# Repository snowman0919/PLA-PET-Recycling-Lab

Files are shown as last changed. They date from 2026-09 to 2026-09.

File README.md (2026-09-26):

# PPR — 균일 직경 필라멘트를 위한 통합 재활용기
목표와 경계는 [KODEX.md](KODEX.md), 현재 증거·작업은 [STATUS.md](STATUS.md), 압출 방법 비교는 [품질 경로 결정 기록](docs/decisions/filament-quality-route.md)을 따른다.

제품 범위: 호퍼 → S1 2축 파쇄 → 선택 이송부 → S2 편심/역자전 분쇄 → 버퍼 → 수평 압출 → 냉각/직경 계측 → 가압 인출 → 장력 분리 권취.
최종 목표는 냉각 후 일정한 1.75mm 필라멘트를 경제적으로 만드는 것이다. 현재 연결 이송과 실제 필라멘트 생산 모두 미완료다.
상류 실패와 별개로 최종 제품의 같은 압출 모듈에 건조 기준 원료를 넣는 설계/디지털 시험을 진행할 수 있다. 전체 제품 성공과는 구분한다.

## 작업 자산
- c2.1/cad/PPR_VP1.step: 전체 기계 STEP
- c2.1/cad/PPR_C2_1_machine_integration.FCStd 및 c2.1/src/: 편집 원본/생성기
- c2.1/bom/system_bom.csv, .xlsx: 활성 BOM
- c2.1/firmware/, electrical/: 제어/전장 자산
- c2.2/sim/assets/usd/full_machine.usda: 대응 Isaac 장면
- c2.2/results/full_machine/layout_comparison.json: 기준안/재배치안 비교
- tests/, c2/tests/, c2.1/tests/, c2.3/tests/: 범위별 회귀 자산

재현은 해당 생성기/실행기의 --help와 결과의 원본 해시·설정을 사용한다. CAD/STEP, 충돌 메시/USD, BOM, 시험 결과를 같은 후보로 맞춘 후 해당 verify_artifacts를 수행한다.
역사 실험의 재실행이나 Graphify 완료를 새 제품 작업의 선행조건으로 만들지 않는다. 숫자·PASS 명칭은 당시 범위에서만 유효하다.
물리 제작·구매·통전·실물시험·main 병합은 사용자 승인 전 HOLD다. MIT 및 LICENSE-HARDWARE를 유지한다.

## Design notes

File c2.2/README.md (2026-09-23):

# C2.2 — VP1 전체 기계 Isaac Sim 검증

`c2.1/cad/PPR_VP1.step`을 전체 솔리드 단위로 변환해
`sim/assets/usd/full_machine.usda`에서 실제 조립 운동과 소재 경로를 검사한다.
현재 STEP/USD SHA와 최종 실행 결과는 루트 `STATUS.md`가 기준이다.

## 주요 경로

- `sim/assets/convert.py`: STEP 솔리드와 조립 이름을 STL/sidecar로 대응시킨다.
- `sim/full_machine.py`: S1/S2/오거/풀러/와인더의 종속 운동과 접촉을 실행한다.
- `sim/flow_localize.py`: 호퍼, S1 배출, 슈트, S2 입구를 단계별로 주입해
  실제 통과·정체·world 이탈을 구분한다.
- `sim/verify_full.py`: 전체 운동 추적, 접촉, 소재 경로 결과를 판정한다.
- `sim/render_reviewer_scenes.py`: 동일 USD/STEP에 묶인 검토 이미지 4장을 만든다.
- `results/full_machine/`: 최종 기계 판독 JSON, runner log, 이미지 증거.

## 검증 경계

이 시뮬레이션은 결함 발견과 디지털 운동/경로 검증이다. 파괴 물성, 처리량,
토크, 열, 마모, 수명과 안전 containment의 물리 적합성을 인증하지 않는다.
PSU는 24V 33A/명판 800W이며 500W는 소프트 목표, 792W는 강제 상한이다.
구매·제작·통전·물리 운전·main 병합은 명시적 승인 전 **HOLD**다.

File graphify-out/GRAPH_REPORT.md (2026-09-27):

# Graph Report - PPR-c2.1-codex-20260921  (2026-09-27)

## Corpus Check
- Incremental host semantic refresh: 2 current documents; corpus-wide statistics were not recomputed.

## Summary
- 2025 nodes · 3721 edges · 192 communities (107 shown, 85 thin omitted)
- Extraction: 92% EXTRACTED · 8% INFERRED · 0% AMBIGUOUS · INFERRED: 301 edges (avg confidence: 0.87)
- Token cost: 0 input · 0 output

## Community Hubs (Navigation)
- architectures.py
- process_model.py
- c2/src/build_cad.py
- verify_contract.py
- guards.py
- EvidenceTests
- drive_teeth.py
- winder.py
- c2.1/src/build_cad.py
- test_telemetry.py
- S2
- i6_surrogate.py
- downstream.py
- run_one_phase
- flow_localize.py
- electrical_bay.py
- convert.py
- test_contract.py
- filament-quality-route.md
- cadquery
- generate
- Inputs
- s1_event
- components
- run_study.py
- engineering.py
- relocated_gravity.py
- bond_manager.py
- test_r03_causality.py
- d4_accounting.py
- run_case.py
- design.py
- render_reviewer_scenes.py
- approx
- main
- C2 Engineering Contracts
- Controller
- os
- ControllerTests
- i3_coupon.py
- PPR C1 Dimensioned Engineering Review Package
- make_drawings.py
- DesignContracts
- controller_core.cpp
- structural_screen.py
- Outputs
- build_machine_integration.py
- chute.py
- build_freecad.py
- analyze.py
- C2.1 S2 Transmission Schematic
- d2_torque.py
- BondManager
- VP1 whole-machine Isaac Sim validation
- csv
- bonds.py
- ADR-002: VP1 체인 경로 vs 동결된 C1 구조물 릴리프 (chain routing reliefs)
- InvalidMechanism
- run_r1.py
- TestVerifier
- Open Physical Actions Register
- _box
- ProcessModelPhysicsTests
- run_r4_t2b.py
- PPR KODEX — 쓸 수 있는 필라멘트를 만드는 가상제품
- auger_shaft
- _prism_xz
- TestD4Ledger
- hopper_panels.py
- run_r2.py
- Fail-Closed Thermal and Jam Control Reference
- DownstreamGeometryTests
- emit_usd.py
- C2.3-A-R3 리뷰 핸드오프 (판정 요청)
- d0_clock.py
- json
- C2.3-A-R1 수렴 재실행 핸드오프 (판정 요청)
- d1_contact.py
- PPR_C2_1_machine_wiring_erc.json
- TestNullStatus
- pan_floor
- _feed_gear
- REVIEW HANDOFF — C2.3-R1 진단 결과 (판정 요청)
- PPR C1 CAD Inspection Image
- hashlib
- Limits
- run_r3.py
- i4_screen.py
- C2.2 핸드오프 — 2층 구조: (a) I0–I6 numpy 프록시 + (b) C2.2b headless PhysX 동역학 Gates A–F
- MissingEvidenceError
- Single-Input Reverse-Output S2 Drivetrain
- worm_sleeve
- power_sim.py
- VP1 current STEP FreeCAD USD BOM assembly
- test_surrogate.py
- STATUS.md
- test_benchmark.py
- C2.2 VP1 실행 씬 출처와 증거 경계
- Fixed C2 System Constraints
- build_machine_wiring.py
- Active C2 Baseline
- FeedbackTests
- C2.2 — VP1 전체 기계 Isaac Sim 검증
- build_system_bom.py
- d3_bond.py
- c2/src/verify_artifacts.py
- REFERENCE/UNRATED worm, wheel, shafts, bearings and motor
- Shared M1 one-degree-of-freedom S1/S2 drive
- check_admissible
- convergence/manifest.json
- r2/manifest.json
- r3/manifest.json
- screen_open_area
- C1 Digital Contracts
- Stage 5 active chute auger
- Function-preserving integration reliefs
- Four-turn auger and transverse screw active chute
- Donor PSU and stop button reported, system cost still unquoted
- s2a_direction_phi
- TestD4Faults
- 24V 33A PSU, 500W soft target and 792W current ceiling
- Digital verification is not physical approval
- VP1 integrated product hard goal
- Clause A1 (Steps-per-run)
- Clause A2 (Metrics calculation)
- Clause A3 (Mass conservation)
- Clause A4 (Missing-event handling)
- Clause A5 (Scene provenance)
- Clause A6 (Break/fragment accounting)
- Clause A7 (Threshold applicability)
- Host-tested firmware power allocation
- Param Trace Document
- Amendment Log
- CONTRACT (superseded)
- Contract Baseline Cutter Gap
- Contract Baseline q
- Contract Baseline Screen Aperture
- Next Checkpoint Plan
- Requirements Evidence
- Review Handoff Summary
- CONTRACT R1
- Conservative cycloidal pin-ring screen
- Material Calibration Evidence
- Motor and Driver RFQ Evidence
- Unsubmitted DEM Job Queue
- C2 Research and CAD Dependencies
- Contact impulse threshold
- Convergence metrics
- Coupling Window Radius
- dt ladder values
- Forbidden actions in R0
- Fragment / bond-break count threshold
- Baseline S1-A (twin-shaft hook shear)
- Baseline S2-A (q=8, e=7 mm)
- Cutter gap
- Impulse scale
- Friction / gravity / solver iterations
- Initial poses
- Screen aperture
- Frozen waste cases (FDM, PURGE, WRAP)
- Goal R0 §2 (Numerical reliability closure)
- Hopper Interior Geometry
- ISAAC_PHYSX backend
- Kinematic Frame F0 Definition
- C2.3 tribometer, crown and joint expansion stopped
- Real-geometry candidate validation method
- Machine Body Dimensions
- Mass conservation threshold
- Motion Law Equations
- Nominal Motion Parameters
- Revision R1
- BLOCKED_PERFORMANCE_DATA
- Required artifacts list
- Residence time threshold
- S1 Cutter Parameters
- S2 Local Frame Definition
- Shaft work threshold
- 가상 품질·비용 비교 (실물 성능 아님)
- comparison_contract
- 6. 경제성 및 다음 작업

## God Nodes (most connected - your core abstractions)
1. `components()` - 41 edges
2. `S2` - 32 edges
3. `Inputs` - 31 edges
4. `Transmission` - 30 edges
5. `BondManager` - 26 edges
6. `_box()` - 26 edges
7. `components()` - 23 edges
8. `generate()` - 22 edges
9. `s1_event()` - 22 edges
10. `_cyl()` - 22 edges

## Surprising Connections (you probably didn't know these)
- `Small Pin-Ring Feasibility Screen` --semantically_similar_to--> `S2 Cycloidal Guide, Sleeve, and Pin Rings`  [INFERRED] [semantically similar]
  c2/docs/C2_ENGINEERING_NOTES.md → drawings/PPR_C1_dimensioned_review.pdf
- `Short clutch fault is not rescued by feedback` --semantically_similar_to--> `Isolated modeled winding-clutch fault`  [INFERRED] [semantically similar]
  STATUS.md → docs/decisions/filament-quality-route.md
- `Frozen C1 Baseline` --conceptually_related_to--> `PPR C1 Dimensioned Engineering Review Package`  [INFERRED]
  README.md → drawings/PPR_C1_dimensioned_review.pdf
- `Evidence and Safety Boundaries` --semantically_similar_to--> `Safety-Preserving Cost Reduction Order`  [INFERRED] [semantically similar]
  AGENTS.md → c2/docs/CALIBRATION_AND_RFQ.md
- `Open Physical Actions Register` --semantically_similar_to--> `Nominal Drawing Fabrication Hold`  [INFERRED] [semantically similar]
  c2.1/docs/OPEN_ACTIONS_KO.md → c2.1/drawings/PPR_C2_1_P6_nominal_plate_review.pdf

## Import Cycles
- None detected.

## Hyperedges (group relationships)
- **Connected material-route verification boundary** — c2_1_docs_adr_002_chain_routing_active_auger, c2_1_docs_adr_002_chain_routing_cross_feed_shaft, c2_1_docs_adr_002_chain_routing_connected_transport_hold, c2_2_readme_flow_localization [EXTRACTED 1.00]
- **C1 RFQ-Only Dimensioned Drawing Set** — drawings_ppr_c1_dimensioned_review_drive_and_bearing_plates, drawings_ppr_c1_dimensioned_review_s1_cutter_system, drawings_ppr_c1_dimensioned_review_s2_cycloidal_components, drawings_ppr_c1_dimensioned_review_interface_and_fit_schedules [EXTRACTED 1.00]
- **C2 and C2.1 Numerical Evidence CI Pipeline** — _github_workflows_c2_engineering_c2_numerical_study_step, _github_workflows_c2_engineering_c2_unit_tests_step, _github_workflows_c2_engineering_gp_performance_training_step, _github_workflows_c2_engineering_mlp_performance_training_step, _github_workflows_c2_engineering_c2_artifact_verification_step, _github_workflows_c2_engineering_c2_1_transmission_step, _github_workflows_c2_engineering_c2_1_unit_tests_step, _github_workflows_c2_engineering_c2_1_artifact_verification_step [EXTRACTED 1.00]
- **C2 P5 Thermal and Control Evidence** — c2_docs_c2_engineering_notes_s2_thermal_development_module, c2_docs_c2_engineering_notes_five_node_thermal_circuit, c2_docs_c2_engineering_notes_cad_derived_heat_capacity_bounds, c2_docs_c2_engineering_notes_cooling_fault_sensitivity, c2_docs_c2_engineering_notes_fail_closed_control_reference, c2_docs_c2_engineering_notes_independent_hardware_safety_chain, c2_docs_c2_engineering_notes_p5_digital_thermal_control_boundary [EXTRACTED 1.00]
- **C2 Performance Evidence Gate** — c2_docs_c2_engineering_notes_performance_job_manifest, c2_docs_c2_engineering_notes_qualified_performance_learning_pipeline, c2_docs_c2_engineering_notes_blocked_performance_data, c2_docs_c2_engineering_notes_material_calibration_plan [EXTRACTED 1.00]
- **C2 S2 Geometry Decision Flow** — c2_docs_c2_engineering_notes_s2_parameter_search, c2_docs_c2_engineering_notes_geometry_assembly_screen, c2_docs_c2_engineering_notes_small_pin_ring_feasibility, c2_docs_c2_engineering_notes_split_dual_path_alternative [EXTRACTED 1.00]
- **Diagnostic Outcomes relate to Requirements** — c2_3_revisions_r1_diagnostic_summary [INFERRED 0.85]
- **Digital Evidence Without External Hardware Release** — _github_workflows_c2_engineering_no_hardware_approval_gate, _github_workflows_c2_engineering_dynamic_evidence_count_contract, _github_workflows_c2_engineering_procurement_fabrication_energization_hold_contract [INFERRED 0.95]

## Communities (192 total, 85 thin omitted)

### Community 0 - "architectures.py"
Cohesion: 0.22
Nodes (16): validate_mechanisms(), Architecture, check_baseline_present(), check_clearance(), check_direction(), I4 mechanism architecture library (Isaac-independent, numpy-free). 7 variants:…, _s1a(), _s1b() (+8 more)

### Community 1 - "process_model.py"
Cohesion: 0.05
Nodes (57): build_library(), library_for_source(), main(), Build the same C++ PI kernel used by the host controller self-test., Avoid stale shared code in process-model calculations., _add(), chute_checks(), _dist_to_s2() (+49 more)

### Community 2 - "c2/src/build_cad.py"
Cohesion: 0.21
Nodes (15): Any, box(), cylinder(), from_c1(), main(), primitive(), C2 S2 thermal/fixed-shear development module. Not an assembly release. C1…, sector() (+7 more)

### Community 3 - "verify_contract.py"
Cohesion: 0.06
Nodes (45): Gate F follow-on: refit surrogate anchors on REAL dynamics data (additive).…, _load(), Gate A-F dynamics contract tests (no SimulationApp: manifest/schema only)., A reused STL path erased the south S1 tread in the executable scene., test_dt_sweep_complete(), test_full_machine_compound_solids_have_distinct_contact_meshes(), test_gap_screen_sweep_complete(), test_s1_runs_real_physics() (+37 more)

### Community 4 - "guards.py"
Cohesion: 0.18
Nodes (16): _box(), components(), guard_chain_a(), guard_chain_b(), guard_lid_interlock_seat(), guard_s2_ring(), VP1 Stage 2: containment guards and lid-interlock seat. Replaces the…, Named guard parts in absolute machine coordinates (group 'guard'). (+8 more)

### Community 5 - "EvidenceTests"
Cohesion: 0.13
Nodes (11): evidence_inventory(), EvidenceError, main(), nondominated(), ndarray, Path, ValueError, training_gate() (+3 more)

### Community 6 - "drive_teeth.py"
Cohesion: 0.09
Nodes (40): legacy_parts(), chain_length_mm(), gear_center_distance(), gear_pitch_radius(), ratio_chain(), Pure kinematics/math for the VP1 common drive — NO cadquery dependency. Split…, Transverse pitch radius of a helical gear (normal module mn)., External tangent construction in XZ. Returns the two touch-point 4-tuples, the… (+32 more)

### Community 7 - "winder.py"
Cohesion: 0.06
Nodes (63): _box(), components(), _cyl(), _flange(), _idler_z(), nip_opening_mm(), nip_range_mm(), pull_cool_mount() (+55 more)

### Community 8 - "c2.1/src/build_cad.py"
Cohesion: 0.06
Nodes (68): analytical_bounds(), c2_process_part(), cad_frame_check(), collision_checks(), components(), cylinder(), export_assembly(), extrude_xz() (+60 more)

### Community 9 - "test_telemetry.py"
Cohesion: 0.09
Nodes (15): aggregate(), load_run(), A2 aggregate: telemetry.jsonl + events.jsonl -> derived quantities. Mass:…, reject_proxy(), ledger(), load_run(), A2 partial mechanical energy ledger (NEVER claims closure). residual = W_in -…, A2 telemetry/analysis tests (>=10): integrals, mass, ledger, convergence, proxy… (+7 more)

### Community 10 - "S2"
Cohesion: 0.15
Nodes (11): design_set(), generalized_torque(), hook_polygon(), kinematics(), point_jacobian(), polygon_area(), ndarray, Six polar controls per hook; linear interpolation is manufacturable, not… (+3 more)

### Community 11 - "i6_surrogate.py"
Cohesion: 0.12
Nodes (23): bo_search(), build_pareto(), dominates(), evaluate_on_rows(), features(), load_i5_rows(), main(), pareto_front() (+15 more)

### Community 12 - "downstream.py"
Cohesion: 0.11
Nodes (30): _bounds(), _box(), build_result(), components(), cool_duct(), cool_fan_3_ref(), _cyl(), gauge_contact_a() (+22 more)

### Community 13 - "run_one_phase"
Cohesion: 0.07
Nodes (23): buffer_throat_contains(), gravity_mouth_contains(), gravity_receiver_contains(), hole_transition(), main(), Path, Return (candidate, completed_hole) for one descending physics step. The…, Sphere envelope inside the actual octagonal Ø13 lower clear throat. (+15 more)

### Community 14 - "flow_localize.py"
Cohesion: 0.15
Nodes (13): FIX A: material-flow localization for the integrated PPR VP1 machine. The last…, # NOTE: the contact-report event stream (subscribe_contact_report_, body_of(), Full-machine motion verification under Isaac Sim 6.1 headless PhysX. Loads the…, Classify a collision prim path into a body token., # NOTE: extra_args is the only channel that reaches the kit process —, bbox(), build() (+5 more)

### Community 15 - "electrical_bay.py"
Cohesion: 0.15
Nodes (24): _box(), components(), contactor(), current_limiter(), din_rail(), driver(), driver_1(), driver_2() (+16 more)

### Community 16 - "convert.py"
Cohesion: 0.11
Nodes (24): _bbox(), candidate_manifest(), _candidate_mass_properties(), _candidate_parts(), git_head(), _lod_of(), main(), Path (+16 more)

### Community 17 - "test_contract.py"
Cohesion: 0.09
Nodes (13): check_executor_label(), _forbidden_labels(), A1 contract tests (stdlib unittest, goal section 22). Banned terminal labels…, Accept only the Isaac Sim / PhysX backend descriptor., Proxy records (analytic diagnostic only) are inadmissible., reject_proxy(), rel_change(), rel_mass_error() (+5 more)

### Community 18 - "filament-quality-route.md"
Cohesion: 0.15
Nodes (14): 269 mm formation-to-gauge feedback dead time, Modeled two-axis observed and true qualification gate, Single-pass feedback A, optional reheating B, same-hardware fixed C comparison, Isolated S2 injection has three same-bore-to-buffer passages, not connected feed, 1. 사용자 결정과 작업 상태, 2. 조사에서 실제로 확인한 것, 3. 현재의 가성비 유력 기준안과 비교, 4. 간단하지만 제품과 연결된 모델 (+6 more)

### Community 19 - "cadquery"
Cohesion: 0.10
Nodes (8): ChainGeometry, ChuteGeometry, GearGeometry, GearRatioKinematics, skipUnless, VP1 Stage 1: real drivetrain geometry + S1->S2 chute tests. CAD-dependent tests…, Tooth-count kinematics recomputed from design/parameters.json., cadquery

### Community 20 - "generate"
Cohesion: 0.12
Nodes (11): build_bond_list(), cell_lattice(), main(), Recover lattice (nx,ny,nz,dx,dy,dz) by regenerating the specimen., Rebuild 6-neighbourhood lattice bonds matching bonds.lattice_graph., generate(), main(), random_quaternion() (+3 more)

### Community 21 - "Inputs"
Cohesion: 0.07
Nodes (27): Inputs, aux_demand_W, band_rotation_ms, buffer_full, estop_closed, fan_required, fan_tach_ok, gauge_major_mm (+19 more)

### Community 22 - "s1_event"
Cohesion: 0.15
Nodes (17): BenchmarkError, _equiv_dims(), _load_dir_for_arch(), main(), RuntimeError, I5 low-resolution end-to-end S1->S2 benchmark (Isaac-independent, numpy).…, Run S1 fracture event; return dataset record + fragment list. threshold_scale…, Feed IDENTICAL saved S1 fragments through S2 arch screen model. eff_scale… (+9 more)

### Community 23 - "components"
Cohesion: 0.12
Nodes (24): auger_bearings(), belt_bearings(), belt_chain(), belt_drum(), belt_follower_sprocket(), components(), cross_feed_bearings(), cross_feed_shell() (+16 more)

### Community 24 - "run_study.py"
Cohesion: 0.17
Nodes (13): Carry thermal state through batch/fan-fault segments; still uncalibrated., Lower-bound heat capacities from generated C2 metal volumes, not measured…, Thermal, thermal_capacities_from_cad(), thermal_duty_run(), thermal_matrix(), thermal_run(), _canon() (+5 more)

### Community 25 - "engineering.py"
Cohesion: 0.19
Nodes (13): diverse_selection(), equivalent_motor_load(), main(), Path, C2 deterministic engineering study. Numerical assumptions are not test evidence., write_json(), fit_gp(), fit_mlp() (+5 more)

### Community 26 - "relocated_gravity.py"
Cohesion: 0.25
Nodes (14): at_box(), gravity_parts(), loft_section(), main(), nominal_mass(), other_parts(), pairs(), Independent, non-release relocated S2 gravity-handoff alternative. Runs against… (+6 more)

### Community 27 - "bond_manager.py"
Cohesion: 0.13
Nodes (15): _components(), find(), union(), FractureInputError, FractureResult, Fragment, NonphysicalError, RuntimeError (+7 more)

### Community 28 - "test_r03_causality.py"
Cohesion: 0.13
Nodes (5): R0.3 causality/accounting unit tests (system python3, isaac-free). >= 10 tests:…, TestAtomicVsComponent, TestD3Distinguishability, TestDiagConstants, TestTimedDisable

### Community 29 - "d4_accounting.py"
Cohesion: 0.16
Nodes (19): compare_metrics(), _isaac_child(), jam_status(), main(), make_buckets(), ordered_sum(), passage_status(), D4 observability / accounting / negative tests (Goal R0 section 4, D4). Isaac… (+11 more)

### Community 30 - "run_case.py"
Cohesion: 0.15
Nodes (19): build_run_config(), dt_label(), dt_source_mapping(), finalize(), _import_s1(), main(), prepare(), A2 single-case Isaac headless runner (ONE frozen case + ONE ladder dt). REUSE… (+11 more)

### Community 31 - "design.py"
Cohesion: 0.13
Nodes (12): copy, box(), cyl(), part(), plate(), PPR C1 dimensional master. Generates a backend-neutral constructive-solid model., ring(), write_all() (+4 more)

### Community 32 - "render_reviewer_scenes.py"
Cohesion: 0.18
Nodes (17): isaac_capture(), look_at_matrix(), main(), probe_positions(), Path, Reviewer scenes for the PPR VP1 full machine (c2.2 acceptance item 2). Renders…, Use only a connected probe run for this exact STEP and USD., RTX attempt with a disk heartbeat. Kit quirk on this host: exceptions raised… (+9 more)

### Community 33 - "approx"
Cohesion: 0.16
Nodes (5): approx(), TestBoundaryWork, TestD0SubstepMapping, TestD1UnitRule, TestShaftTorque

### Community 34 - "main"
Cohesion: 0.12
Nodes (20): main(), mesh_volume(), Path, FIX B(1): convex-hull fidelity audit for the integrated machine. For every…, Signed volume of a closed triangle mesh via the divergence theorem (mm^3). CAD-…, Sample a centre and 16 rim rays of each Ø3 screen exit in mesh XY., screen_vertical_mesh_paths(), sha256_file() (+12 more)

### Community 35 - "C2 Engineering Contracts"
Cohesion: 0.11
Nodes (18): Run C2.1 Artifact Verification, Run C2.1 Transmission Analysis, Run C2.1 Unit Tests, Run C2 Artifact Verification, C2 Engineering Contracts, Run C2 Numerical Study, Run C2 Unit Tests, Actual Run Counts Must Equal Dynamic Evidence Inventory Counts (+10 more)

### Community 36 - "Controller"
Cohesion: 0.12
Nodes (18): Controller, BAND_ROTATION_PERIOD_MS, command_, gauge_gate_, gauge_seen_, integral_, latched_, limits_ (+10 more)

### Community 37 - "os"
Cohesion: 0.13
Nodes (12): argparse, Gate A loader: open c2.2/sim/assets/usd/machine.usda headless, report stage…, fail(), main(), I0 SimulationApp smoke: headless stage + one rigid cube, 60 physics steps. Gate…, # NOTE: close() os._exit()s via fast shutdown on success, so the JSON, Gate B: PhysX S1 twin-shaft (S1-A) + waste fragment clusters + breaking bonds.…, # NOTE: NO use_backend("tensor") scope: the ContactSensor (+4 more)

### Community 38 - "ControllerTests"
Cohesion: 0.15
Nodes (5): allocate_power(), Controller, Reference admission only; PSU 792 W rating does not raise this budget., controller(), ControllerTests

### Community 39 - "i3_coupon.py"
Cohesion: 0.19
Nodes (13): check_ordering(), load_dir_for(), main(), OrderingError, RuntimeError, I3 single-event fracture smoke benchmark (Isaac-independent, numpy-only). 12…, Fixed-lattice probe: identical geometry+seed, class strengths vary. Elementwise…, P0/P1 strand bundles carry no fracture claim (wrap risk only). (+5 more)

### Community 40 - "PPR C1 Dimensioned Engineering Review Package"
Cohesion: 0.12
Nodes (17): BLOCKED_PERFORMANCE_DATA, C1-SEED Comparison Point, Coupled Kinematic Work Model, Eccentric Sleeve Wall Constraint, Geometry and Assembly Screen, PLA PET and TPU Calibration Plan, 144-Job Performance Manifest, Qualified GP and MLP Performance Learning Pipeline (+9 more)

### Community 41 - "make_drawings.py"
Cohesion: 0.21
Nodes (16): ezdxf, reportlab_lib_pagesizes, reportlab_pdfbase, reportlab_pdfbase_ttfonts, reportlab_pdfgen, shapely_ops, dim(), drawshape() (+8 more)

### Community 43 - "controller_core.cpp"
Cohesion: 0.16
Nodes (15): algorithm, array, band_count(), diameter_pi_step(), main(), PowerDevice, name, W (+7 more)

### Community 44 - "structural_screen.py"
Cohesion: 0.19
Nodes (14): ast, bending_point(), case(), flange_thickness(), literal_dict_assignment(), margin(), Bounded, non-qualifying structural and thermal screen for VP1 hardware. Run:…, Read dimension constants without importing CadQuery or regenerating CAD. (+6 more)

### Community 45 - "Outputs"
Cohesion: 0.14
Nodes (14): Outputs, admitted_W, aux_enable, fans_enable, gauge_in_tolerance, h100_enable, h60_enable, m1_enable (+6 more)

### Community 46 - "build_machine_integration.py"
Cohesion: 0.18
Nodes (17): assembly_geometry_checks(), imported(), bbox_overlap(), bounds(), c21_parts(), collision_audit(), extent(), main() (+9 more)

### Community 47 - "chute.py"
Cohesion: 0.15
Nodes (12): bypass_channel_floor(), cutter_sweep_solids(), _guide(), _prism_xy(), VP1 Stage 1: real transfer chute from the S1 discharge opening to the C2.1 S2…, Conservative S1 cutter sweep envelopes for clearance checks., No stationary ribs in the screw pickup or flight zone., Longitudinal U cradle, opened locally into the powered cross pickup. The old… (+4 more)

### Community 48 - "build_freecad.py"
Cohesion: 0.23
Nodes (11): main(), Create the native FreeCAD C2.1 machine assembly from checked STEP parts., read_shape(), freecad, part, build(), face(), primitive() (+3 more)

### Community 49 - "analyze.py"
Cohesion: 0.12
Nodes (19): main(), Gate F: real gap x screen sweep on survivors (thin driver). S1 gap sweep: shaft…, run(), itertools, scipy_linalg, scipy_optimize, shapely_geometry, allocate() (+11 more)

### Community 50 - "C2.1 S2 Transmission Schematic"
Cohesion: 0.15
Nodes (15): F0 Coordinate Frame: +X Right, +Y Shaft Axis, +Z Up, C2.1 S2 Transmission Schematic, Elastic Sharing, Ratings, and Fabrication HOLD, Fixed q+1 Ring Pins and Reaction, Front Input Support, M1 Input Shaft +ω, Nominal Window Clearance extra0.20mm, Not a Generated CAD Section (+7 more)

### Community 51 - "d2_torque.py"
Cohesion: 0.21
Nodes (14): boundary_work(), _cross(), _dot(), _isaac_child(), on_post(), main(), D2 torque/work semantics diagnostic (Goal R0 section 4, D2). Definitions…, Axial contact torque on ONE shaft. contacts: iterable of (position_p,… (+6 more)

### Community 52 - "BondManager"
Cohesion: 0.18
Nodes (11): BondManager, Deterministic fallback fracture over a BondGraph., fixed_lattice(), I3 fracture regressions: determinism, conservation, orderings, gaps. Evidence:…, TestDeterminism, TestInvalidInput, TestMassConservation, TestOrientationDependence (+3 more)

### Community 53 - "VP1 whole-machine Isaac Sim validation"
Cohesion: 0.14
Nodes (14): Connected particulate transport HOLD, CROSS_FEED_SHAFT transverse screw, Rear output plate feed-mount clearance, S2 negative-direction geometry sweep, Historical proxy-result exclusion, Development PR versus physical-release policy, VP1 STEP/USD and result provenance, Stage-wise material flow localization (+6 more)

### Community 54 - "csv"
Cohesion: 0.18
Nodes (7): Verify the C2.1 P0-P6 digital package without granting hardware approval., csv_rows(), InventoryCostTests, Reported donor and stop-button inventory is not qualified stock., csv, xml_etree_elementtree, zipfile

### Community 55 - "bonds.py"
Cohesion: 0.15
Nodes (13): graph_from_meta(), Rebuild the exact I2 lattice from waste_gen metadata. Mirrors…, Bond, BondGraph, Cell, lattice_graph(), I2 bond-graph: cells/chunks + directional bonds (nominal strengths only).…, 6-neighbourhood lattice; x->in_raster, y->cross_raster, z->inter_layer_z. Cell… (+5 more)

### Community 56 - "ADR-002: VP1 체인 경로 vs 동결된 C1 구조물 릴리프 (chain routing reliefs)"
Cohesion: 0.15
Nodes (12): ADDENDUM (2026-09-22, VP1 Stage 4, rev B — SUPERSEDES the rev A decision), ADDENDUM 3 (2026-09-23, VP1 Stage 5 활성 오거 — 연결 이송 HOLD), ADDENDUM 4 (2026-09-23, VP1 횡방향 이송과 S2 출력 지지판), ADR-002: VP1 체인 경로 vs 동결된 C1 구조물 릴리프 (chain routing reliefs), REV B 부록 2 (2026-09-22, Isaac 통합 피드백 2건), 검증 경계와 HOLD, 결정 (rev B), 결정 (부품별) (+4 more)

### Community 57 - "InvalidMechanism"
Cohesion: 0.18
Nodes (10): main(), screen_candidate(), check_envelope(), get(), InvalidMechanism, ValueError, Zero clearance, bad direction sign, missing baseline, bad envelope., TestEnvelope (+2 more)

### Community 58 - "run_r1.py"
Cohesion: 0.23
Nodes (10): build_case_geometry(), _isaac_child(), main(), R1 runner: one canonical case at ONE ladder dt, equal 2.4 s physics. Contract:…, # NOTE: Gf.Vector3f hard-crashes (SIGSEGV) in this Isaac build;, # NOTE: work integral requires tau_shaft from typed contacts;, Deterministic per-case fragment positions from waste_gen dims., run_case_dt() (+2 more)

### Community 60 - "Open Physical Actions Register"
Cohesion: 0.17
Nodes (12): C2.1 Digital Assembly Service and Test Package, Lockout and Staged Physical Test, DIGITAL_P0_P6_PACKAGE_PASS_PHYSICAL_RELEASE_HOLD, P6 Full Machine Digital Integration, Remaining Rating and Performance Holds, Motor Floor Exceeds System Soft Budget, Open Physical Actions Register, C2.1 P0-P6 Integration Plan (+4 more)

### Community 61 - "_box"
Cohesion: 0.17
Nodes (12): _box(), bypass_wall_north_lower(), bypass_wall_south(), guide_left(), guide_right(), South containment, relieved only at the low-y spur-gear face., North containment ends before the orthogonal screw's west cheek., Central lane wall; transverse screw supplies lateral transport. (+4 more)

### Community 63 - "run_r4_t2b.py"
Cohesion: 0.17
Nodes (9): R4-T2b: chain suspended via end posts (FixedJoint), NO pin, gravity + preload…, isaacsim, isaacsim_core_experimental_objects, isaacsim_core_experimental_prims, isaacsim_core_experimental_utils_stage, isaacsim_core_simulation_manager, omni_physx, omni_timeline (+1 more)

### Community 64 - "PPR KODEX — 쓸 수 있는 필라멘트를 만드는 가상제품"
Cohesion: 0.18
Nodes (10): PPR KODEX — 쓸 수 있는 필라멘트를 만드는 가상제품, Hard Rules, 현재 상태와 방법, 목표, 산출과 인수, 품질·가성비 방향, Chiron donor reuse and reference pellet procurement boundary, C2.1 Active Digital Iteration (+2 more)

### Community 65 - "auger_shaft"
Cohesion: 0.25
Nodes (11): auger_shaft(), _cross_feed_flight(), cross_feed_shaft(), _helix_z(), _path_frame(), Split shaft with a swept, opposite-hand screw and keyed spur., Point and unit tangent at the initial vertex of a swept helix., Single right-hand helicoid with a 3 mm swept flight face. (+3 more)

### Community 66 - "_prism_xz"
Cohesion: 0.13
Nodes (15): belt_loop(), capsule(), intake_lip(), _prism_xz(), Historical ratchet rib retained for inspection, not installed., Historical pan-only ribs, superseded by the active transfer design., 45deg intake lip under the S1 -X side strip (the opening's west edge); all…, Two side loops leave a continuous, separately driven central lane. (+7 more)

### Community 68 - "hopper_panels.py"
Cohesion: 0.40
Nodes (9): _bore(), components(), _inner_y(), _nut_boss(), Split the historical C1 hopper BRep into bounded PC panels and steel seam…, Return two distinct PC print solids and two steel bolted seam straps. The split…, _strap(), ocp_brepextrema (+1 more)

### Community 69 - "run_r2.py"
Cohesion: 0.29
Nodes (8): R2 Review Handoff Summary, build_case_geometry(), _isaac_child(), main(), R2 runner: per-physics-step contact stream + signed shaft load + boundary work…, run_case_dt(), run_paths(), sha256_file()

### Community 70 - "Fail-Closed Thermal and Jam Control Reference"
Cohesion: 0.25
Nodes (11): CAD-Derived Heat-Capacity Lower Bounds, Clean-Air Cooling Path, Clean Filter, Clogged Filter, and Fan-Failure Sensitivity, Fail-Closed Thermal and Jam Control Reference, Five-Node Chamber and Drivetrain Thermal Circuit, Fixed-Shear Sensor Path, Independent Hardware Safety Chain, P5 Digital Thermal and Control Boundary (+3 more)

### Community 72 - "emit_usd.py"
Cohesion: 0.36
Nodes (9): box_mesh(), convex_hull_of_verts(), git_head(), load_stl_verts_faces(), main(), mesh_prim(), Path, Gate A: machine USD emission from staged STL + parametric DERIVED transfer… (+1 more)

### Community 73 - "C2.3-A-R3 리뷰 핸드오프 (판정 요청)"
Cohesion: 0.20
Nodes (9): 1. R3 결과 요약, 2. T1 상세 (5% GATE_MET), 3. T2 BLOCKED 상세 (픽스처 반복 이력), 4. 리뷰어 지시 반영 상태, 5. 미해결 (리뷰어 승인 필요), 6. 실행자 결론 불가, 7. CI 상태 (정확 커밋 a431df75), 8. R4-T2b 추가 반복 (리뷰어 승인 fixture 변경 실행 결과) (+1 more)

### Community 74 - "d0_clock.py"
Cohesion: 0.31
Nodes (7): _isaac_child(), main(), D0 clock + 2.4 s horizon diagnostic (Goal R0 section 4, D0). Minimal scene:…, Child body: runs under the Isaac venv python; one dt only., run_dt(), run_paths(), sha256_file()

### Community 75 - "json"
Cohesion: 0.09
Nodes (26): VP1 Stage 4 rev 2: S2 negative-rotation direction audit (Isaac evidence). The…, PowerGateTests, Behavioral regressions for reference-feed extrusion and gauge geometry., VP1 material choices and bounded mass properties for STEP-derived solids. These…, Gate E: 3-level dt sweep on one W1 + one W4 case (thin driver over s1_physx).…, Full-machine USD emission for the CAD-derived integrated assembly. Reads…, I2 deterministic waste taxonomy generator (stdlib + numpy only). Classes: W1…, I4 architecture + screening regressions (Isaac-independent). Evidence:… (+18 more)

### Community 76 - "C2.3-A-R1 수렴 재실행 핸드오프 (판정 요청)"
Cohesion: 0.22
Nodes (8): 1. 구현, 2. 실행, 3. 수렴 (주 쌍 0.0025 vs 0.00125), 4. 수렴하지 않은 항목 (정직 기록), 5. overall_numerically_converged = True의 의미, 6. 미해결 (리뷰어 승인 필요), 7. 실행자 결론 불가, C2.3-A-R1 수렴 재실행 핸드오프 (판정 요청)

### Community 77 - "d1_contact.py"
Cohesion: 0.20
Nodes (8): _isaac_child(), main(), D1 contact units + isolation diagnostic (Goal R0 section 4, D1). Exact…, run_one(), run_paths(), sha256_file(), R0.2 analytic unit tests: D0 mapping + D1 unit rule + D2 torque/work cases.…, TestDiagConstants

### Community 78 - "PPR_C2_1_machine_wiring_erc.json"
Cohesion: 0.25
Nodes (7): coordinate_units, date, included_severities, kicad_version, $schema, sheets, source

### Community 80 - "pan_floor"
Cohesion: 0.25
Nodes (8): _c21_transform(), _obstruction_solid(), pan_floor(), Apply the frozen c2_subassembly_transform to a c2 local-frame part., Frozen S2 jacket solids that pierce the chute floor plane: the…, S1 discharge basin with a recessed, supported belt pocket., Landing ledge over the mouth (x 278.5..310, y 255..295); cut where the frozen…, trough_floor()

### Community 81 - "_feed_gear"
Cohesion: 0.25
Nodes (8): cross_feed_gear(), cross_feed_idler(), _feed_gear(), pdl_feed_gear(), Six-mm, 12T involute spur face, keyed on its +X bore flank., 12T keyed output gear sharing the existing PDL shaft., 12T integral intermediate wheel on its own two supported journals., Equal 12T keyed output wheel; two external meshes restore PDL sign.

### Community 82 - "REVIEW HANDOFF — C2.3-R1 진단 결과 (판정 요청)"
Cohesion: 0.25
Nodes (7): 1. 구현 (작성 파일 — 커밋 없음), 2. 실행 (진단별 결과 — 수치), 3. 수렴 (해당 없음 — R0는 진단, 수렴 판정 아님), 4. 미수렴 (해당 없음), 5. 미해결 (리뷰어 승인 필요 — 실행자가 해소 불가), 6. 실행자 결론 불가 항목, REVIEW HANDOFF — C2.3-R1 진단 결과 (판정 요청)

### Community 83 - "PPR C1 CAD Inspection Image"
Cohesion: 0.36
Nodes (8): BRep Mesh Inspection View, Cutting Mechanism, Drive Components, Filament Spools, Hopper and Lid Hidden for Visibility, PPR C1 CAD Inspection Image, PPR C1, Structural Frame

### Community 84 - "hashlib"
Cohesion: 0.15
Nodes (15): Host-build the portable controller core; no target flash or energization., load(), main(), Build deterministic P0-P6 + VP1 digital status and artifact manifests., sha256(), A4 verifier tests (>=8): tamper detection, recompute checks. Forbidden terminal…, deck(), main() (+7 more)

### Community 85 - "Limits"
Cohesion: 0.29
Nodes (6): Limits, jam_current_A, jam_minimum_rpm, maximum_temperature_C, operational_cap_W, stale_feedback_ms

### Community 86 - "run_r3.py"
Cohesion: 0.33
Nodes (6): _isaac_child(), main(), R3 runner: staged sustained-contact diagnostics T1/T2/T3. Reviewer-approved…, run_paths(), run_stage_dt(), sha256_file()

### Community 87 - "i4_screen.py"
Cohesion: 0.27
Nodes (7): lhs(), ndarray, ValueError, I4 cheap geometric/kinematic screening (Isaac-independent, numpy LHS). Samples…, sample_candidates(), ScreenInputError, TestSamplerDeterminism

### Community 88 - "C2.2 핸드오프 — 2층 구조: (a) I0–I6 numpy 프록시 + (b) C2.2b headless PhysX 동역학 Gates A–F"
Cohesion: 0.29
Nodes (6): (a) I0–I6 numpy 프록시층 (유지, UNCALIBRATED ordering smoke), (b) C2.2b 실제 headless PhysX 동역학 Gates A–F (Isaac 6.1.0.0, `c2.2/results/dyn_*`), C2.2 핸드오프 — 2층 구조: (a) I0–I6 numpy 프록시 + (b) C2.2b headless PhysX 동역학 Gates A–F, HOLD / 미해결 (승인 없이 진행 금지), 게이트 테이블, 리비전

### Community 89 - "MissingEvidenceError"
Cohesion: 0.33
Nodes (6): MissingEvidenceError, RuntimeError, Raised when calibrated (measured) strength data is requested. No physical…, Calibrated fracture strength lookup — always fails loudly (no data)., require_calibrated_strength(), TestMissingEvidence

### Community 90 - "Single-Input Reverse-Output S2 Drivetrain"
Cohesion: 0.33
Nodes (6): Fixed-Ring Cycloid Selection Rationale, Pin-Window Offset Coupling, Single-Input Reverse-Output S2 Drivetrain, Split Dual-Path Alternative, Torque and Reaction Path, Unverified Rating and Fabrication Limits

### Community 91 - "worm_sleeve"
Cohesion: 0.33
Nodes (6): auger_wheel(), _helix_about_y(), Right-hand helix advancing along +Y with a specified bottom phase., PDL_WORM: right-hand two-start swept threads keyed to the shaft., Sector gear at the auger end, generated against the actual worm. The swept worm…, worm_sleeve()

### Community 92 - "power_sim.py"
Cohesion: 0.38
Nodes (6): admitted_load(), demand_at(), main(), VP1 Stage 4: virtual duty-cycle power simulation over the nameplate table.…, (demands, stage) at time t_s. loads = {key: W}., Mirror firmware admission; unknown/denied aux holds the entire line.

### Community 93 - "VP1 current STEP FreeCAD USD BOM assembly"
Cohesion: 0.25
Nodes (8): Three-fan cooling thermal sensitivity and geometric apertures, Smalley ES-16 dimensional candidate without project load rating, SSB-0087 published work height incompatible with present clutch seat, Thrust washer radial margin is conditional not a strength claim, SSB-0087 rated work height is not matched by 1 mm clutch seat, VP1 current STEP FreeCAD USD BOM assembly, Motion sample cross-runtime SHA and current CI status, ES-16 groove and washer stop spool escape, with axial float

### Community 94 - "test_surrogate.py"
Cohesion: 0.20
Nodes (4): I6 surrogate + Pareto + robustness regressions (stdlib+numpy+unittest).…, TestGroupedSplit, TestRobustnessBounds, TestSchema

### Community 95 - "STATUS.md"
Cohesion: 0.22
Nodes (10): User accepted NVIDIA EULA and matched Isaac native trial ran, 100 g/h feed window and same-particle S1-S2-buffer HOLD, Phase-sampled S2 feed and BRep geometry screen, Current same-ID S1 to S2 to buffer native flow remains HOLD, Isaac matched eight-cycle connected flow stops before S2 mouth, 상류 연결 및 인수 경계, Modeled spool radius starts growing only after material reaches nip, 100 g/h design feed and no flake or moisture specification (+2 more)

### Community 96 - "test_benchmark.py"
Cohesion: 0.15
Nodes (6): I5 end-to-end benchmark regressions (Isaac-independent, numpy-only). Evidence:…, TestBaselinePresent, TestS1Determinism, TestSameInputIdentity, TestSchema, TestTorqueScaling

### Community 97 - "C2.2 VP1 실행 씬 출처와 증거 경계"
Cohesion: 0.40
Nodes (4): C2.2 VP1 실행 씬 출처와 증거 경계, 디지털 검증과 물리 검증의 구분, 정책, 활성 원본

### Community 98 - "Fixed C2 System Constraints"
Cohesion: 0.40
Nodes (5): PPR C2 Engineering Baseline, 136-Row Cost Review Ledger, Fixed C2 System Constraints, JSS57BLY Motor Candidate Evidence, Shared-Motor Load Envelope

### Community 99 - "build_machine_wiring.py"
Cohesion: 0.36
Nodes (6): connector_symbol(), main(), Generate the review-only KiCad machine wiring schematic and pin/net ledger., uid(), write_schematic(), uuid

### Community 100 - "Active C2 Baseline"
Cohesion: 0.50
Nodes (4): Active C2 Baseline, Evidence and Safety Boundaries, Fixed System Constraints, Safety-Preserving Cost Reduction Order

### Community 102 - "C2.2 — VP1 전체 기계 Isaac Sim 검증"
Cohesion: 0.50
Nodes (3): C2.2 — VP1 전체 기계 Isaac Sim 검증, 검증 경계, 주요 경로

### Community 103 - "build_system_bom.py"
Cohesion: 0.36
Nodes (7): column_name(), main(), Build the active C2.1 system BOM without mutating the historical C1 BOM., rows(), write_xlsx(), collections, xml_sax_saxutils

### Community 104 - "d3_bond.py"
Cohesion: 0.31
Nodes (7): _isaac_child(), main(), D3 two-body coupling causality diagnostic (Goal R0 section 4, D3). CONSTRAINT…, run_one(), run_paths(), sha256_file(), Diagnostic Summary

### Community 105 - "c2/src/verify_artifacts.py"
Cohesion: 0.24
Nodes (7): evaluate(), main(), Full incremental procurement coverage. A missing quotation is not zero cost., candidate_hashes(), canonical_sha256(), _canon(), Check active C2 evidence and CAD integrity without authorizing hardware.

### Community 106 - "REFERENCE/UNRATED worm, wheel, shafts, bearings and motor"
Cohesion: 0.67
Nodes (3): Keyed PDL, auger, S2 and jackshaft torque paths, REFERENCE/UNRATED worm, wheel, shafts, bearings and motor, Single 15T/40T helical mesh

### Community 107 - "Shared M1 one-degree-of-freedom S1/S2 drive"
Cohesion: 0.67
Nodes (3): S2 single-input reference kinematics, Shared M1 one-degree-of-freedom S1/S2 drive, VP1 fixed electrical, envelope, budget and material constraints

### Community 108 - "check_admissible"
Cohesion: 0.40
Nodes (4): check_admissible(), OversizeError, ValueError, TestHopperReject

### Community 112 - "screen_open_area"
Cohesion: 0.50
Nodes (3): Open-area fraction proxy: hole pitch ~ 2x diameter triangular grid. Returns…, screen_open_area(), TestScreenArea

### Community 117 - "Donor PSU and stop button reported, system cost still unquoted"
Cohesion: 0.40
Nodes (5): Donor PSU and stop button reported, system cost still unquoted, 500 W operating cap leaves 76 W before unselected auxiliary motors, 권취 링 보유 치수 후보와 예압 정격 HOLD, Reported Chiron PSU and E-stop do not establish product cost, Modeled 424 W base and unqualified 20 W auxiliary example

### Community 118 - "s2a_direction_phi"
Cohesion: 0.50
Nodes (3): S2-A law: phi = -theta/q (reverse, sign -1)., s2a_direction_phi(), TestS2ADirection

### Community 189 - "가상 품질·비용 비교 (실물 성능 아님)"
Cohesion: 0.50
Nodes (4): Short clutch fault is not rescued by feedback, Reported donor stock and no reference pellets for staged test, Replacement PSU and stop-button seller screen is not current cost, 가상 품질·비용 비교 (실물 성능 아님)

### Community 191 - "6. 경제성 및 다음 작업"
Cohesion: 0.67
Nodes (3): Chiron donor reuse is conditional on interface and condition, PSU and stop button listings are fallback purchases only, 6. 경제성 및 다음 작업

## Knowledge Gaps
- **244 isolated node(s):** `검증 경계`, `주요 경로`, `runs`, `schema`, `runs` (+239 more)
  These have ≤1 connection - possible missing edges or undocumented components. (Counts symbols only; 844 node(s) total have ≤1 connection when file, concept and rationale nodes are included.)
- **85 thin communities (<3 nodes) omitted from report** — run `graphify query` to explore isolated nodes.

## Suggested Questions
_Questions this graph is uniquely positioned to answer:_

- **Why does `C2.1 Active Digital Iteration` connect `PPR KODEX — 쓸 수 있는 필라멘트를 만드는 가상제품` to `filament-quality-route.md`, `STATUS.md`?**
  _High betweenness centrality (0.021) - this node is a cross-community bridge._
- **Why does `7. 같은 제품의 기준 원료 모델·제어·비용 비교 (VP1)` connect `winder.py` to `filament-quality-route.md`?**
  _High betweenness centrality (0.018) - this node is a cross-community bridge._
- **What connects `검증 경계`, `주요 경로`, `runs` to the rest of the system?**
  _244 weakly-connected nodes found - possible documentation gaps or missing edges._
- **Should `process_model.py` be split into smaller, more focused modules?**
  _Cohesion score 0.05336538461538461 - nodes in this community are weakly interconnected._
- **Should `verify_contract.py` be split into smaller, more focused modules?**
  _Cohesion score 0.06259426847662142 - nodes in this community are weakly interconnected._
- **Should `EvidenceTests` be split into smaller, more focused modules?**
  _Cohesion score 0.12698412698412698 - nodes in this community are weakly interconnected._
- **Should `drive_teeth.py` be split into smaller, more focused modules?**
  _Cohesion score 0.08826945412311266 - nodes in this community are weakly interconnected._

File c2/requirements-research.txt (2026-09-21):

numpy
scipy
shapely
# Optional CAD backend; generated STEP files are included.
cadquery==2.8.0
# Only needed once qualified performance records exist:
scikit-learn
joblib
torch

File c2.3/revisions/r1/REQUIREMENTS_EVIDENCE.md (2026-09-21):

# R0 §2 Requirements-to-Evidence Table (R1, checkpoint R0.1)

> Scope: Goal R0 §2 amendments R1–R6. No threshold is relaxed: numeric values are
> unchanged; R1 narrows *applicability*.
> Thresholds (work 5%, impulse 5%, residence 10%, discrete-count 10%, mass 1e-6
> relative) apply ONLY to valid + observable + comparable quantities.
> Quantities that are null, censored, NOT_IMPLEMENTED, NOT_APPLICABLE, or
> diagnostic-only are excluded from threshold comparison entirely: they are
> neither within-threshold nor outside-threshold; no comparison is evaluated.
> Executor terminal labels: IMPLEMENTED / BLOCKED / FAILED only.
> `c2.3/STATE.json` is a progress file, never a baseline constant.

| ID | Requirement (R0 §2 as amended) | Evidence artifact | Verifier check | Threshold applicability |
|----|---|---|---|---|
| R1 | Equal MEASURED physics duration: 2.4 s shared by every ladder dt [0.01, 0.005, 0.0025, 0.00125]; per-dt substeps 240 / 480 / 960 / 1920; engine-reported sim time plus per-callback step ID and dt recorded in telemetry. | Per-run config {dt_s, substeps, measured_duration_s}; telemetry columns {engine_time_s, callback_step_id, callback_dt_s}; run summary sim_time_s. | substeps × dt == 2.4 s per run; engine_time_s monotone non-decreasing with terminal == 2.4 s within the documented float handling; callback_step_id dense 1..substeps with matching callback_dt_s. | None: protocol condition, not a compared quantity. Cross-dt metric comparison is admissible only while this row holds. |
| R2 | Contact/joint evidence is correctly typed raw telemetry from the engine path. Legacy scalar R×sum\|F\| torque/impulse estimates are diagnostic-only and inadmissible as evidence. | Typed telemetry schema doc + per-step raw contact force vectors / joint effort readings with source + unit + type labels; any legacy derived series kept under diagnostics/ only. | Schema type check per column; work/impulse integrals in the evidence path reference raw typed columns only; convergence inputs contain no legacy-derived series. | Work 5% and impulse 5% apply only to integrals accumulated from raw typed telemetry on comparable runs. Legacy-derived values receive no threshold evaluation. |
| R3 | Missing events default to null plus an observability status: wrap → null / NOT_IMPLEMENTED; screen transit → null / NOT_APPLICABLE where no screen claim exists (e.g. S1-only); residence → right-censored value with censor flag, never a point value; jam → NOT observable, no flag emitted. | Events file with null payloads + status enum column; schema doc defining the four statuses. | Every null payload carries a status; no default false/zero event flags in evidence; residence rows carry the censor flag; no jam column in the evidence schema. | Residence 10% and discrete-count 10% apply only to observed, uncensored, comparable events. Censored / null rows are excluded from comparison. |
| R4 | Mass closure by runtime actor/material accounting with separated buckets active / output / removed / missing. Forcing unexplained deficit to zero is prohibited. Relative tolerance 1e-6 with explicit float handling (dtype, summation order, comparison form). | Per-run mass ledger {m_initial, m_active, m_output, m_removed, m_missing, m_unexplained, rel_error} + float-handling note. | Recompute rel_error = \|m_initial − accounted\| / m_initial; buckets reconcile to accounted; m_unexplained row present and unforced (may be nonzero — the threshold judges it, the writer does not erase it). | Mass 1e-6 relative applies only when all four buckets are present on comparable runs. |
| R5 | Only a minimal mechanically-coupled bond diagnostic is admitted: joint- or conservative-force-coupled representation; bond condition in {intact, disconnected, timed-disable}. Bare counters are inadmissible. | Bond diagnostic record with coupling declaration + per-bond condition labels + transition log. | Condition enum check; coupling declared and joint-typed or conservative-force-typed; bare counter series absent from evidence inputs. | Discrete-count 10% applies only to mechanically-coupled diagnostic counts that are observable and comparable. Bare counters receive no threshold evaluation. |
| R6 | Scene export + hash mandatory per run (or per frozen-case scene). A reference CAD hash attests inputs only and is not run evidence. | Exported scene file + sha256 recorded in the run manifest; reference hashes labeled provenance-only. | Recompute scene sha256 and compare with the manifest; confirm no convergence or threshold input cites a reference CAD hash. | None: provenance condition, not a compared quantity. |

## Notes

- N1. The legacy equal-steps ladder (240 steps at every dt; physics duration varying
  2.4 / 1.2 / 0.6 / 0.3 s) is superseded. Its runs are not comparable evidence under
  R1 and MUST NOT be reused for convergence claims.
- N2. The old "jam/wrap identical across primary pair" rule is retired as a
  consequence of R3: jam is NOT observable and wrap is null / NOT_IMPLEMENTED, so
  there is no observed flag pair to compare. This retires a vacuous comparison; it
  relaxes nothing.
- N3. Normative contract: `c2.3/revisions/r1/CONTRACT_R1.md`. Clause history:
  `c2.3/revisions/r1/AMENDMENT_LOG.md`. The file `c2.3/CONTRACT.md` is superseded
  as a normative document and preserved unmodified as a historical record.

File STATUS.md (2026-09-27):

# PPR 현재 상태
검토: 2026-09-27. 목표·제약은 `KODEX.md`, 판단 근거는 `docs/decisions/filament-quality-route.md`를 따른다. 사용자 확인 보유품은 **2NC 비상정지 버튼 1개와 기존 Anycubic Chiron 도너 프린터 및 그 PSU**다. PSU **24V 800W·외형 240×120×65mm**, 버튼 **35×35mm**는 사용자의 추가 보고이며 명판·독립 실측·장착구멍·보호상태와 버튼의 치수 대상/모델/접점 정격·회로는 미확인이다. 프린터 세부품과 별도 기준 펠릿 보유도 미확인이다. **규격 내 필라멘트의 실제 연속 생산은 입증되지 않았다.** 이전 Stage 6 보고의 20mm 제어 지연·129g/h·4mm/200ppm 확정·가상 수율의 물리 입증 주장은 철회한다.

## 동일 제품의 현재 디지털 후보
- 전체 조립 `c2.1/cad/PPR_VP1.step` SHA256 `c3620578…`: 269 객체/300 STEP 솔리드 재수입 유효, 본체 630×414×510mm, 운전 외곽 847×414×510mm. 신규/유지품 경계 BRep 간섭과 S2 로터-고정 이송계 5° 위상 표본 및 보수적 연속 간격 경계 통과(`c2.1/results/machine_integration.json`). 편집 가능한 `PPR_C2_1_machine_integration.FCStd` 228/228 유효 객체와 300 STL 자산/`c2.2/sim/assets/usd/full_machine.usda`는 같은 STEP 해시를 출처로 확인했다. USDA SHA256 `d528db25…` 정적 방출/pxr 파싱, 인출 스프링 공간 2개 Mesh의 충돌 비활성 확인 및 스크린 STL 광선 78홀 표본 통과는 Isaac native 입자 이송 검증이 아니다. **작동 중 입자·필라멘트 연속 이송, 강도, 조립 공차는 이 결과로 증명되지 않는다.**
- 기준 원료는 생산 버퍼를 빼고 냉간 새들에 교체 장착하는 별도 `SERVICE-HOPPER`로 투입한다. S2/M1 정지 상태만 가정하며 덮개 안전 인터록·밀봉·공급 성능은 HOLD. 이는 완제품에서 쓰는 같은 압출·냉각·계측·인출·권취부를 시험하기 위한 서비스 입력이며 상류 성공 판정이 아니다.
- 하류는 2축 Hall-레버/광학 **후보** 게이지, 관통 냉각 공기창 2개와 셋째 팬 참조/가동 후드, 중앙에 필라멘트를 놓는 니프 롤러와 프레임/정지좌, 키드 칼라·미선정 스프링 자리·마찰 패드의 권취 클러치 참조 형상을 통합했다. 기존에 떠 있던 인출 프레임·냉각 트레이에는 후면 Al 직립재→강관 `PULL_COOL_MOUNT`→니프 프레임/트레이 바닥의 CAD 면접촉 경로, 권취 베어링·모터에는 앞쪽 Al 직립재→강재 `WIND_MOUNT`→양쪽 베어링/모터의 면접촉 경로를 추가했다. 이전에 헐거운 권취 드럼이 +Y로 3mm 무접촉 이동하던 결함에 대해서는 Ø16 축의 ES-16 **치수 후보** Ø15.02×1mm 홈 2개·공칭 환형 링 포락선 2개·Ø30/Ø16.2 와셔 1개로 이탈 정지 경로를 모델링했다. 그러나 링/홈 공차만으로 한쪽 0.06..0.24mm, 두 곳 합계 최대 0.48mm 축유격이 있으며, 실제 2회 감김 링 형상·예압은 모델링하지 않았다. SSB-0087 스프링 후보는 Ø16 축을 피하지만 공표 작업높이1.57mm가 현행1mm 자리보다0.57mm 커서 **정격 작동점 부적합**; 1mm에서의 압축 가능성/하중은 미확인이고 62.3N을 권취 토크에 적용하지 않았다. 링·와셔 강재 가정 질량은 약4.90g으로 감소했으나 업체 견적과 제조 가능성은 미확인이다. 기존 거의 실심 드럼을 2mm 강관+내부 웹으로 고쳐 후보 강재 밀도에서 플랜지 포함 회전 질량 3.118→1.814kg, 정지 랙/마운트 약0.707+0.295kg 추가(`c2.1/results/winder_geometry.json`). 슬롯/볼트·트레이/팬/계측 체결·용접 강도·동적 균형·실제 제작비는 HOLD. 실제 냉각 유효 길이, 센서 정확도·투명재/TPU 대응, 니프 접촉력, 링/홈 피로·축추력, 클러치 예압·토크·드럼 접합도 미입증.
- 인출 니프의 이전 조정 롤러 CAD는 회전 롤러·캐리지·Y축 스프링을 하나로 융합하여 별도 회전과 수직 순응을 동시에 할 수 없었다. 현재 동일 하류 후보는 Ø20/Ø6 회전 아이들러, 두 Ø6.04 보어의 별도 이동 캐리지, Ø5 수직 가이드·두 스프링 **공간 포락선**(설치 높이 8.5..7.0mm) 및 상하 금속 정지좌(니프 1.5..3.0mm)로 분리했다. 최소/공칭 필라멘트/최대 위치에서 내부 BRep 간섭이 없고 기구학적 이격이 유지된다. `winder_geometry.json`의 `grip_qualified=false`, `path_check.json`의 `nip_force_status=HOLD_UNSELECTED_SPRING_BEARING_AND_GRIP`: 실제 베어링/가이드 공차·스프링 정격·축 고정·접촉력/슬립·TPU 변형/마모·조립 단가가 미확정이므로 이 CAD 결과는 실제 1.75±0.05mm 필라멘트 그립/생산 증명이 아니다.
- 호스트 C++ 제어기에는 2축 직경 PI, 결측 시 품질 HOLD, 시동/정지 미확인 구간 및 보조 구동 요구부하 판정이 있다. 호스트 빌드의 28개 자가시험은 통과했지만 타깃 빌드·배선 연동·안전 릴레이 실물시험을 대체하지 않는다. 가상 공정 비교는 이 C++ PI 커널을 호출하나 전체 펌웨어 동작을 실행하지 않는다.
현행 로컬 `c2.1/tests` 전체 50개(19개 건너뜀), `c2.2/tests/test_material_mass.py` 3개, `path_check.py`의 13개 기하 경계, `verify_artifacts.py`의 추적 산출물 192개 해시 검사 통과. PR의 첫 CI에서는 교차 런타임 `motion_samples.json` 해시가 달랐다(#36308568559); 생성기는 운동 궤적의 |좌표|<10⁻¹²mm 삼각함수 잔차만 0으로 직렬화하고 독립 검증 잔차는 유지한다. 로컬 NumPy 2.5.3과 별도 1.26.4에서 동일 SHA256 `480fbe74…` 확인 후 게시된 CI는 C2 #36309372857 및 C2.3 #36309372805 성공, C1 #36309372819는 이미 있던 `src/design.py` 기준 해시 불일치로 실패했다. **현행 로컬 ES-16 치수·인출 니프·권취 모델·2축 계측 판정·재고 재분류 및 STEP/USDA/새 native 결과는 원격 PR에 아직 게시하지 않았다.** `validation_summary.json`은 현행 국부시험 해시 일치·연결시험 `LOCALIZED_BLOCKED`, `material_flow.status=HOLD`, 물리 시험 `DID_NOT_RUN`이다. USDA 자체는 정적 방출이며 그 뒤 Isaac native 동역학을 따로 실행했다.

## 가상 품질·비용 비교 (실물 성능 아님)
`c2.1/results/downstream_route_comparison.json`의 PLA 100g/h, 목표 1.75±0.05mm, 미보정 물성/열전달/유량/센서 가정에서 다이 x540→게이지 x809는 **269mm(약 28.9초)** 피드백 사장거리다. 게이지→니프 20mm는 형성된 재료의 후속 이동이다. 240초 복합 교란에서 정속 C는 1,591.67/1,938.13mm, 피드백 A는 835.73/1,100.30mm 규격 내/니프 도달; A는 146초 계측 결측으로 HOLD되어 서로 생산 길이가 다르며 170..178초 권취 클러치 고장을 겪지 않는다. 이를 분리한 8초·10N 가상 장력 고장에서는 C 1,871.07/1,938.13mm, A 1,877.34/1,944.49mm로 양쪽 모두 약 67mm가 규격 밖이다. 8N 그립 임계·슬립률·클러치 토크는 **미선정 가정**이며 피드백이 이 짧은 고장을 구제했다는 결론은 없다. 지속 +20% 유량의 같은 모델에서는 C 0/1,945.58mm, A 1,401.48/2,247.74mm. 90초 정상 구간에도 다이→니프 잔류 약 290mm는 미확인으로 제외했다. **C/A 중 하나의 실물 품질·경제적 우월성을 확정하지 않는다.** 재가열 정형 B는 압력·열이력·전력 데이터 부족으로 비순위 HOLD.
가상 권취 반경은 이전에 니프 도달 전에도 증가했으나 이제 니프 도달 길이만 누적한다. 정상 90초 PLA 모델은 첫 니프 31.1초 반경 35.0000mm, 마지막 니프 35.1359mm이며 종단 미확인 289.65mm는 권취로 세지 않는다. 니프→스풀 경로·실제 클러치 토크는 이 계산에 없다.
2축 가상 계측 판정의 결함을 수정했다: 과거 고정속도 70초 PLA 모델은 **모델 참값 1.75mm/양 계측축 1.85mm**(+0.10mm 편향)인데 니프 도달 362.29mm를 전량 합격 처리했다. 현행 `quality_summary`는 모델 참값 두 축과 계측 두 축 모두 허용범위·축차를 만족하고 냉각 준비된 길이만 인정해 해당 조건 0mm다. C++ 제어기는 운전 중 명시적 축 불량에 즉시 품질 HOLD하지만 가상 모델은 종전에는 1초 넘는 표본 부재로만 처리했다. 40..40.4초 짧은 단일축 불량에서도 이전 모델은 중단하지 않았으나 현행은 40.0초에 중단한다. 새 표본만 잠시 없을 때에는 1초 초과 후 중단한다. 한 축만 145..153초 불량인 별도 240초 실행은 정속 C 미계측 74.51mm/니프 도달 1,945.58mm, 피드백 A는 145.0초 중단/잔류 미확인 289.05mm; A의 니프 도달분 1,062.34mm가 전량 규격 내여도 전체 생성 1,351.39mm 중 확인 비율은 **78.61%**다. 이는 미보정 모델의 가상 결과이며 센서 교정·실제 수율을 증명하지 않는다.

`c2.1/results/power_sim.json`: M1/M2 및 팬 정격이 미선정인 기준 staged 부하 424W, 500W 상한의 보조 구동 허용 잔여 76W. 임의 보조 20W를 넣은 *시험 입력*의 444W/여유56W를 실제 명판값으로 사용하지 않는다. 보조 구동값 미확인 또는 거부 시 호스트 제어는 M2를 멈춘다. 팬 토출·냉각, 밴드 30초 슬롯의 릴레이 수명/열회복, 보호 회로는 HOLD. 현행 시스템 BOM 210행 중 **2NC 버튼·Chiron 도너 PSU 2행은 사용자 보유 보고**이며 PSU 24V 800W·240×120×65mm와 버튼 35×35mm도 사용자 보고다. 실물 명판·장착면/구멍·정격/안전 자격은 미확인이다. 기존 C1 인계 보유·0원 중 다른 9행은 부품별 도너 재사용 가능성/치수·인터페이스 확인 또는 재견적 대상이다. 도너 프로파일은 길이 미실측이며 프레임·모터·히터를 자동 배정하지 않는다. 210행 모두 착지가격 미견적이고 `known_landed_total_KRW=null`은 무료가 아니라 총 제작 견적 부재다. 과거 조회 모터 후보 110,200원은 100,000원 soft limit 대비 10,200원 초과(드라이버·감속·가공·안전·배송 대부분 제외); 모든 모터 최저가나 전체 초과액은 아니다. 별도 기준 원료·안전회로·적격 구동/프레임·물리 승인 없이 동일 제품의 단계적 하류 실물 검증도 HOLD다.
저가 조달 스크린: 보유 Chiron PSU가 적격 판정을 받으면 **신규 PSU 구매는 불필요**하다. 국내 12/24V 800W 선택형 PSU 상품 표시 95,000원(+게시 배송2,500원)과 AliExpress S-800-24는 *도너 불합격 시 대체 후보*일 뿐이다. 국내품은 24V 옵션별 가격·보고된 240×120×65mm 외형과의 적합성·안전/정격 미확인; Ali 첫 기본 **110V 표시가 58,000원은 한국용 220V 견적이 아니고** 제목 24V 33A는 792W, 외형/인증/배송도 미확인이다. 보유 버튼과 다른 DECA 2NC 15,000원 상품도 대체 후보만이다. 사용자가 요청한 **기준 PLA 펠릿 견적만** 확인했다: 국내 태강 1kg 표시가 11,000원+전국 기본배송4,000원=조건부 **15,000원**(등급·로트·건조/수분 미제시), 해외 ARTME Ingeo 4043D 0.5kg €5.04+게시 전세계 2kg 이하 배송 €25=조건부 **€30.04**(한국 체크아웃·포장중량·세금·환율 미확인). 다른 통화·중량이며 전체 착지가격이나 실물 품질 우위를 입증하지 않는다. `quality_component_candidates.csv`와 결정 기록 §6 참조. 전체 시스템 BOM·안전 적합성도 미확정이고 **원료 주문/선정/시험 승인 없음**.

## 상류 연결 및 인수 경계
하류 수용 설계 유량은 `design/parameters.json`의 **100g/h**이며 실측이 아니다. 정속·무기포 원형만 가정한 ±0.05mm의 이상적 공급 편차 약 -5.63..+5.80%, 269mm 상당 재고 약 0.802g은 실제 버퍼 용량/원료 크기/수분 기준을 결정하지 않는다. `chute.py`의 측면 이송 스윕 반경 6.7→7.2mm와 국소 바닥 릴리프/인계 경사로는 정적 BRep·단위시험에서 간섭 없이 모델링됐다. 사용자가 NVIDIA EULA 수락을 명시해 **현행 STEP `c3620578…`/USDA `d528db25…`의 Isaac native** 연결 시험을 수행했다. 단일 M1 입력 8사이클·12,800스텝·200 입자에서 구동 비율 추적 통과, S1 출구 115/200·스크루 픽업 33/200, **S2 실제 입구 0/200·스크린 보어 0/200·버퍼 0/200**으로 `LOCALIZED_BLOCKED`다(`c2.2/results/full_machine/selected_connected_flow_summary.json`). 같은 형상의 별도 22개 입자씩 주입한 국부시험은 S1 배출 11개 픽업/5개 전진, 슈트 입구 4개 x335 통과/실제 S2 입구 0개였고, S2 내부 직접 주입만 3개가 보어→버퍼를 통과했다(`flow_localize/results.json`). 국부 주입을 동일 입자의 연속 이송으로 합치지 않는다. 충돌 접촉 이벤트 스트림은 이 실행에서 0이며 막힘 부품 이름은 최종 근접 scene-query 진단이지 접촉 충격 계측이 아니다. **상류 동일 입자 연결·안정 공급·실물 필라멘트는 HOLD**다.
같은 STEP/USDA와 Ø3mm 국부 주입 22개에 체류시간만 60→96초(0.0025초 간격, M1 5→8사이클) 늘린 Isaac native 시험에서 x335 통과는 4→6개였지만 실제 +Y S2 입구는 계속 **0/22**였다(`flow_localize/selected_chute_residence_summary.json`). 표본 입자 하나는 (345,231.9,339.2)→(359.1,232.5,319.1)mm로 떨어졌다. CAD에서 공칭 출구 바닥 상자는 S2 축 기준 최대 반경 63.290mm라서 y234..260의 로터 회피 절삭 반경 63.5mm 안에 **전부 제거된다**. 넓은 받이 날의 축방향 여유는 0.329mm, 좁은 꼬리 날의 연속 보수 경계에 대한 추가 반경 여유는 0.09mm뿐이다. 따라서 바닥 높이 조정·날 연장만으로 안전한 연결을 주장하지 않는다. 인계 구조/배치를 재설계하고 동일 형상의 BRep 전 위상 및 native 동일 입자 연결 재시험이 필요하며, 현행 제품의 공급·제작 승인은 HOLD다.

다음 실제 입력: 보유 Chiron PSU의 명판·출력 전류/보호·상태 및 보고된 240×120×65mm 외형의 장착구멍·냉각 간격 독립 확인과 500W 단계 부하 검토, 프린터의 프로파일 길이/단면·모터축/STEP-DIR 드라이버·히터/센서/팬·체결/기계 상태별 재사용 적합성, 보유 2NC 버튼의 35×35mm 대상 부위/패널 절개·장착 깊이와 라벨·제조사/MPN·접점 정격/강제개리 자료 및 실제 안전 회로·물리 lockout 확인. 나머지 모터/드라이버·팬·히터·보호기·베어링/롤러/스프링/체결재의 공급사 치수·정격·한국 착지가격과 전체 제조 견적, 별도 기준 펠릿의 재질/등급·건조/수분·공급률, 기준핀/마이크로미터·게이지 교정, 실제 프레임 슬롯/웹·체결 위치와 랙 볼트·용접·피로/진동 평가, 냉각 트레이/팬/계측 체결, ES-16 제조사 설치도면·축 재질 및 홈 공차, 스프링 재선정/압축량/마찰토크·베어링 축추력, 실제 다이·롤러·냉각·권취 길이별 필라멘트 측정이 필요하다. 독립 물리 lockout 및 사용자 확인 전 cutter/screw/heater/mains 시험을 완료로 표시하지 않는다. 구매·가공·통전·실물시험·main 병합은 승인 전 HOLD; 개발 브랜치 디지털 변경과 별개다.

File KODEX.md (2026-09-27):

# PPR KODEX — 쓸 수 있는 필라멘트를 만드는 가상제품

## 목표
폐출력물·purge를 처리해 냉각 후 직경이 일정한 1.75mm 필라멘트를 경제적으로 생산할 수 있는 통합제품을 만든다. 성공 기준은 분쇄 횟수·STEP 솔리드 수가 아니라 규격 내 필라멘트의 연속 생산성과 제작 가능성이다. 전체 제품 생성→실제 형상/공정 모델 시험→중요 결함 수정→재생성을 반복한다.

이번에는 압출·냉각·직경 측정·인출·권취를 이송 실패 뒤에 세워두지 않는다. 최종 제품에 들어갈 동일 하류 모듈을 건조·선별된 기준 원료로 먼저 설계·시험하고 S1/S2 연결 개선과 병행한다. 임시 폐기형 시제품이나 PET병 전용기로 목표를 바꾸지 않는다. 기준 원료 시험은 전체 폐기물 처리 성공과 구분한다.

## 품질·가성비 방향
초기 설계 목표는 냉각 후 1.75±0.05mm, 개선 목표 ±0.03mm다. 달성 성능이 아니다. 서로 직교하는 직경, 타원도, 길이별 편차·허용범위 이탈·기포/표면·규격 내 생산길이/질량을 평가한다. 평균 1.75나 센서 해상도만으로 합격시키지 않는다. 계측 정확도·기준물 보정·접촉 변형·미관측 구간을 구분한다.

우선 비교 기준은 단순 단축 스크루+온도 제어+재료별 건조/선별+조절 가능한 냉각+저가 직경 계측에 따른 풀러 속도 제어+장력 분리 권취다. 같은 하드웨어의 정속/수동 측정 기준과 비교해 자동 계측의 이득을 확인한다. 냉각 후 측정, 이송 지연, 풀러 미끄럼, 스풀 반경 변화, 500W 히터 스테이징의 온도 영향을 함께 본다. 냉각 방식·센서·구동 선택은 비교 근거로 바꿀 수 있다.

사용자가 본 1.75mm 커스텀 노즐 반복 통과법은 원영상 미확인이다. 재가열 정형/인발/재압출 중 실제 공정을 구분하고 단일 패스와 추가 정형 패스를 비교한다. 노즐 구경=최종 직경으로 가정하거나 반복 가열을 기본 해법으로 고정하지 않는다. 온도·유량·인출·냉각·막힘·열이력·추가 비용을 보고 채택/보류한다. 가는 구간·기포·타원도까지 자동 복원된다고 주장하지 않는다.

최저 부품값보다 전체 비용 대비 규격 내 수율을 우선한다. 현재 사용자 확인 보유품은 **2NC 비상정지 버튼 1개, 기존 Anycubic Chiron 프린터와 그 PSU**다. 사용자가 PSU를 **24V 800W, 외형 240×120×65mm**로, 2NC 버튼을 **35×35mm**로 보고했다. 이는 명판·독립 실측·모델/설치면·장착구멍·보호상태·회로 적합성 확인이 아니며, 버튼 35×35mm가 어느 부분의 치수인지는 미확인이다. 프린터의 프레임재 길이, 모터/드라이버 신호·축, 히터/센서 등은 부품별 조사 전까지 현행 BOM에 적합 재고로 배정하지 않는다. C1 인계의 나머지 보유·0원 9항목을 자동 재사용하지 않는다. 별도 기준 원료 펠릿은 보유 보고가 없고 사용자는 현재 **구매 없는 후보 견적**만 요청했다. 센서·건조·구동·가공·배송·실패 손실을 포함한다. 상용 완제품, 산업용 계측·멜트펌프·진공 정형을 기본 구매안으로 두지 않는다. 필요성이 입증되면 비교한다. AliExpress 등 저가 판매처도 같은 정격·기하·안전·배송/수입·반품 경계로 검토하고 미견적을 0원으로 보지 않는다. 전체 제작 견적과 안전·저비용 대안을 비교한 뒤 soft limit 조정을 협의하며 그 전 지출 승인은 아니다.

## Hard Rules
- S1은 통상적 2축 역회전 커터 스택, S2는 편심 공전+저속 역자전 사이클로이드 착안 분쇄기다. 공용 M1의 실제 감속·분배·구속 경로로 구동하고 압출 M2는 별도다. 모터 미선정. 풀러/권취 보조 구동도 비용·전력에 포함한다. 이상 기어/체인 구속은 허용하되 독립 위치 명령을 동력 전달 증거로 쓰지 않는다.
- PSU 24V 800W, 240×120×65mm, 운전 상한 500W, 본체 700×420×520mm. 전체 추가 구매·가공·안전부품·배송 100,000원 soft limit. 초과 시 최소 기능안·대안·차액을 제시하며 안전을 삭제하지 않는다.
- 원료 PLA/PET/TPU는 재질·등급·열이력별로 분리한다. PET와 PETG를 혼동하지 않는다. 적층물·purge·줄뭉치를 구분하되 purge 강성을 일괄 가정하지 않는다. 구성재 PLA/ABS/PC/알루미늄/강재는 부위별 물성·출력 방향/벽/인필·단면·접합·온도와 연결한다.
- 원본 /home/monad/develop/PPR의 미커밋 작업과 보존 브랜치를 변경하지 않는다. 활성 작업본도 기존 변경을 보존한다. 구매·발주·가공·통전·실물시험·main 병합은 승인 없이 하지 않는다.

## 현재 상태와 방법
작업: /home/monad/develop/PPR-c2.1-codex-20260921
저장소 snowman0919/PLA-PET-Recycling-Lab, 기존 개발 브랜치/PR #5.
HEAD·STATUS·실행 결과부터 확인한다. 능동안과 실제 중력 재배치안은 모두 연결 기능 HOLD인 비교 자산이다. 기존 좌표·부품·문서를 지키려 전달장치를 계속 추가하지 않는다. S1/S2·버퍼·압출부를 함께 배치하고 인계 횟수·무게·제작비를 줄인다. 중력/능동 어느 쪽도 정답으로 강제하지 않는다. 상류 입도·공급 안정성 목표는 하류 압출기의 수용능력과 품질 요구에서 정한다.

Isaac headless/Python은 제품의 구동·간섭·입자 경로에 사용한다. 용융·냉각·직경 제어는 질량수지·열·이송 지연의 간단한 별도 공정 모델로 먼저 연결한다. 강체 구가 다이를 통과한 것을 압출 성공으로 해석하지 않는다. 모델·문헌·실측을 구분하고 필요한 물성만 상세화한다. 데이터가 유효하고 설계 선택에 도움이 될 때만 ML을 쓴다. C2.3 독립 solver/tribometer 연구로 돌아가지 않는다.

메인 에이전트가 방법·도구·작업 분해·배치·코드 수정을 자율적으로 결정한다. 국부 조사는 실제 제품 결함에 필요한 만큼만 한다. 기준 완화·기능 삭제·데이터 조작으로 성공을 만들지 않는다. 문서·Graphify·과거 phase 완료는 제품 개발의 선행조건이 아니다.

## 산출과 인수
전체 STEP, 편집 가능한 CAD, 대응 Isaac 씬/BOM, 압출·직경 제어 코드와 공정 모델, 후보별 비용/품질 근거를 같은 선택 제품에 연결한다. 이번 도착점은 실제 제작 인터페이스가 있는 하류 모듈과 전체 조립, 직경 변동/센서 결함/공급 변동/권취 장력에 대한 실행 기록이다. 규격 내 연속 생산은 추후 물리 검증 전까지 주장하지 않는다. 상류는 동일 입자의 S1→S2 실제 보어→버퍼 연결 시험을 별도로 유지한다.

KODEX가 활성 목표/경계이며 과거 계약·release 명칭은 이를 대체하지 않는다. STATUS는 현재 후보·증거·우선 결함만, 상세 근거는 docs/decisions/filament-quality-route.md에 둔다. 컨텍스트 재개와 주요 선택 때 KODEX/STATUS를 다시 확인한다. 의미 있는 변경은 기존 브랜치에 commit/push하고 PR을 갱신한다. 최종 보고는 변경 제품·실행한 시험·비용·품질 한계·필요한 실물 입력을 구분한다.

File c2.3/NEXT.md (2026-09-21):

# R0.1 checkpoint — Goal R0 §2 revision R1 (draft, reviewer authorization pending)

- Normative draft: `c2.3/revisions/r1/CONTRACT_R1.md`; evidence table
  `c2.3/revisions/r1/REQUIREMENTS_EVIDENCE.md`; history
  `c2.3/revisions/r1/AMENDMENT_LOG.md`.
- `c2.3/CONTRACT.md` is superseded as a normative document; preserved unmodified
  as a historical record (never edit).
- R0 status tracked in `c2.3/STATE.json` field `r0_status`; frozen baseline values
  unchanged. STATE.json is a progress file, never a baseline constant.
- Legacy equal-steps 12-run ladder (240 steps every dt) is superseded as evidence;
  MUST NOT be reused for convergence claims. Next implementation step: R1 §5 equal
  measured 2.4 s ladder (substeps 240/480/960/1920) with typed raw telemetry.

# C2.3-A NEXT — A2 / A3 / A4 only

## A2 — telemetry + work/impulse/energy accounting implementation

- Implement `c2.3/sim/run_case.py`: frozen-case PhysX runner with fixed
  seeds, fixed dt per invocation, frozen initial poses, real hole-geometry
  screen; per-step telemetry (shaft angle/torque, per-fragment contact
  force, bond-break events, fragment poses/velocities, screen passage
  events, residence timers) per goal §12.
- Implement `c2.3/sim/aggregate.py`, `c2.3/sim/convergence.py`,
  `c2.3/sim/energy_ledger.py`: shaft-work integration, contact-impulse
  accumulation, mass accounting with relative mass_error
  (goal §13), mechanical energy ledger, primary-pair convergence ratios.
- Implement `c2.3/tests/` unit tests for telemetry schema, work/impulse
  integrators, ledger closure, and threshold evaluators on fixtures.
- No threshold, baseline, or case edits during A2; any defect in frozen
  values → STOP + BLOCKED per CONTRACT.md §7.

## A3 — fixed-state timestep sweep execution + convergence evaluation

- Execute the frozen-state dt ladder [0.01, 0.005, 0.0025, 0.00125] s on
  FDM (W1/PLA/seed 7), PURGE (W4/PLA/seed 11), WRAP (P0/seed 7, S1-only).
- Evaluate the primary pair 0.0025/0.00125 against frozen thresholds:
  shaft work 5%, contact impulse 5%, residence 10%, relative mass_error
  <= 1e-6 (goal §13), jam/wrap identical, fragment/bond 10%.
- Append per-run sha256 hashes to `c2.3/results/baseline_manifest.json`;
  record energy-ledger closure per run. Executor reports
  IMPLEMENTED / BLOCKED / FAILED only.

## A4 — independent verifier + evidence package + review handoff

- Implement and run the independent verifier (recompute hashes, re-check
  convergence ratios, confirm no proxy inputs, confirm no forbidden
  B/C/D content) over the A2/A3 artifacts.
- Assemble the evidence package: frozen manifests, run summaries,
  telemetry, convergence and energy-ledger records.
- Write `c2.3/REVIEW_HANDOFF_KO.md` for reviewer determination.
  Executor reports IMPLEMENTED / BLOCKED / FAILED only.

## FUTURE / REVIEWER AUTHORIZATION REQUIRED

- Phase B (calibration/physical tests), Phase C (optimization incl.
  gap/screen/motor), Phase D (architecture/ML changes): NOT authorized.
  Commence only with explicit reviewer authorization.

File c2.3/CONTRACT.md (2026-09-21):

# C2.3-A CONTRACT — Numerical Reliability Closure (IMMUTABLE)

> Authorized phase: **C2.3-A only**. Executor: Muse Spark 1.3 / OMP Vibe.
> Executor holds NO determination authority. Terminal phase judgment rests
> solely with the reviewer. Executor final reported values are restricted to
> IMPLEMENTED / BLOCKED / FAILED only.

## 1. Authorized scope

- Phase C2.3-A = numerical reliability closure: Isaac/PhysX timestep
  convergence + mechanical energy accounting.
- Required backend: **Isaac Sim 6.1.0.0 via `$HOME/env_isaacsim-c22`
  (PhysX)**. Any non-PhysX substitute is a proxy and is banned (§4).

## 2. Reviewer policy

- Reviewer holds sole authority for terminal phase judgment.
- Executor never self-assigns terminal standing and never declares
  completion/acceptance language for the phase or its artifacts.

## 3. Frozen baseline (BASELINE ONLY — never optimal)

- S1-A: twin-shaft hook shear, 40 rpm counter-rotating.
- S2-A: q=8, e=7 mm, input +120 rpm / output −15 rpm, phi = −theta/q.
- Cutter gap 0.8 mm — BASELINE ONLY (never optimal, no optimization).
- Screen aperture 4.0 mm — BASELINE ONLY (never optimal, no optimization).
- Waste cases (frozen):
  - FDM = W1 PLA seed 7.
  - PURGE = W4 PLA seed 11.
  - WRAP = P0 seed 7 — S1-only, no S2 fracture claim.
- impulse_scale = 0.02 N·s — UNCALIBRATED assumption, frozen for A-phase.
- Friction / gravity / solver iterations: frozen at C2.2 dynamics defaults;
  any change requires a contract amendment by the reviewer before use.
- Initial poses: frozen per-case (S1 nip-drop placement; S2 drop above
  screen plane); identical handoff states feed S2-A/S2-B comparisons.

## 4. Proxy ban

- No analytic / surrogate / size-comparison substitute for contact,
  breakage, passage, residence, or energy quantities.
- S2 passage determined by rigid-body contact against real hole geometry
  only. `impulse_scale` stays UNCALIBRATED throughout C2.3-A.

## 5. dt ladder

- Ladder: [0.01, 0.005, 0.0025, 0.00125] s.
- Primary convergence pair: 0.0025 / 0.00125.
- Same steps-per-run within a comparison; fixed seeds; fixed backend.

## 6. Convergence metrics

- Continuous: shaft work, contact impulse, residence time,
  output/screen mass.
- Discrete: break/fragment count, jam flag, wrap flag.

## 7. Thresholds (goal §18, frozen)

- shaft work: 5%.
- contact impulse: 5%.
- residence time: 10%.
- mass conservation: relative mass_error <= 1e-6 (goal §13; if the fracture representation makes this mathematically impossible, STOP + BLOCKED, do not change the threshold).
- jam / wrap flags: identical across primary pair.
- fragment / bond-break count: 10%.

**Thresholds frozen after first commit; contract mistake → STOP + BLOCKED.**
No threshold edit after the A1 commit without reviewer authorization
recorded as a new contract revision. If this contract misstates goal §18
or any frozen baseline value, the executor MUST STOP and report BLOCKED
instead of proceeding.

## 8. Required artifacts

- `c2.3/CONTRACT.md` (this file), `c2.3/STATE.json`, `c2.3/NEXT.md`.
- `c2.3/configs/baseline.json`, `c2.3/configs/cases.json`.
- `c2.3/results/baseline_manifest.json` (run hashes appended at A3).
- dt-ladder run summaries + telemetry, energy-accounting record (A2/A3).

## 9. Forbidden in C2.3-A

- Commencing phases B / C / D.
- gap / screen optimization, motor selection, ML training/selection,
  architecture change or re-ranking.
- Any physical-test or calibration claim; physical_runs stays 0.

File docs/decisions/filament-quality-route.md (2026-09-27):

# 결정 기록 — 저비용 1.75mm 필라멘트 품질 우선 경로
검토일: 2026-09-27
상태: 초기 비교 기준 선정. 물리 검증/견적 완료 또는 전역 경제 최적점 확정이 아니다.
정책은 루트 KODEX.md가 우선한다. 이 문서는 근거와 선택지를 보존하며 새 승인 사다리가 아니다.

## 1. 사용자 결정과 작업 상태
- 최종 목표는 폐출력물/purge에서 실제로 쓸 수 있는 균일 직경 필라멘트다. 분쇄와 프로브 이송은 수단이다.
- 전체 제품을 먼저 만들고 실제 형상 시험으로 개선한다. 최종 제품에 사용할 동일 압출 모듈의 기준 원료 주입은 허용하되, 상류 성공이나 임시 폐기형 시제품으로 취급하지 않는다.
- 초기 직경 설계 목표 1.75±0.05mm, 개선 목표 ±0.03mm. 물리 달성 여부는 미확인이다.
- 검토 당시 로컬/PR HEAD b1e02a99c672cfff1b5311668656f407c06f1707. 기준안/재배치안 모두 동일 입자의 버퍼 목 연결 0/200, 직경 측정 기반 필라멘트 생산은 미입증이다. 과거 로컬 변경과 시험은 STATUS/원자료에서 다시 확인한다.
- 500W hard cap, 본체700×420×520mm, 전체 추가비10만원 soft limit, M1 공유/M2 별도 유지. 단계적 동작으로 전력·공급을 분리할 수 있으나 모터·안전·유량 가정을 감추지 않는다.
- 사용자가 본 “1.75mm 커스텀 노즐 반복 통과” 영상은 링크/제작자를 확인하지 못했다. 특정 YouTube 프로젝트로 동일시하지 않는다. 영상 확보 전에도 비교 가능한 정형 경로를 검토한다.

## 2. 조사에서 실제로 확인한 것
[S1] Felfil의 공식 제품 설명은 냉각 후 직경 측정, 측정값에 따른 풀러 속도 조정, 권취 클러치로 장력 분리를 설명한다. 원리 참고이며 제품 구매 또는 판매자의 정밀도를 PPR 달성값으로 인용하지 않는다.
[S2] Filabot은 균일 직경을 위해 용융 온도, 냉각, 인출/권취 속도를 함께 조절하고 인라인 측정으로 확인하는 운영을 설명한다.
[S3] InFiDEL은 저비용 보정형 직경 센서의 공개 설계다. 원래 프린터의 유량 보정용이므로 압출 제어기로 그대로 동작한다고 가정하지 않는다. “<$5”는 프로젝트의 공표 비용이지 현재 한국 배송 포함 2축 계측계 견적이 아니다.
[S4] Petsiuk/Pearce의 공개 연구는 다축 광학 직경·표면 관측과 스풀 길이별 결함 기록을 다룬다. 저비용 카메라 경로의 근거지만 PPR의 정확도·투명재/TPU 적합성은 별도 확인이다.
[S5] Filastruder는 PLA 건조·냉각, 원료 크기·오염 관리와 반복 열이력을 주의사항으로 제시한다. 이 제조사의 5mm 투입 규격이나 사용자 공차 보고는 해당 기계의 사례이며 PPR 사양이 아니다.
[S6] Recreator3D는 PET#1 병을 대상으로 한 재사용 부품 기반 pultrusion이다. 불규칙 PLA/PET/TPU 출력물·purge를 모두 처리하는 PPR의 대체안은 아니다.

## 3. 현재의 가성비 유력 기준안과 비교
A. 단일 패스 용융 압출 + 가변 냉각 + 저가 직경 폐루프 + 독립 장력 권취
- 기존 설계의 단축 스크루/히터/풀러 **형상·인터페이스만** 후보로 재사용한다. Chiron 도너 PSU/프레임/모터·가이드/팬·열부품의 개별 치수·정격·제어 인터페이스가 맞을 때만 실물 재사용으로 배정하고, 부족하거나 부적합한 부품과 가공만 신규 견적에 넣는다(§6). 건조·선별과 공급 안정화, 교체 가능한 다이, 필요할 경우 지지된 멜트 필터를 포함한다.
- 정상 온도/스크루 속도를 안정화하고 냉각 후 직경의 오차를 풀러 속도로 보정한다. 권취 반경 변화가 인출 속도를 결정하지 않도록 장력을 분리한다.
- 2축 저접촉력 Hall/레버형과 공개 광학 방식을 후보로 두며 교정·표면 마찰·TPU 변형·투명재·전자부품/기구 비용을 비교한다.
- 지금 가장 먼저 구현·비교할 구조다. 아직 견적 또는 실물 검증으로 경제 최적점이 확정된 것은 아니다.

B. 추가 가열 정형 다이/노즐
- 사용자가 제안한 방식의 비교 경로다. 입력이 용융물, 이미 굳은 스트랜드, 병 스트립 중 무엇인지부터 구분한다.
- 기본 압출 후 0회/추가1회 정형을 먼저 비교한다. 반복 횟수 증가는 품질 이득과 에너지·수율·열이력·운전 부담의 근거가 있을 때만 한다.
- 다이 입구 테이퍼/랜드/실제 보어 공차/온도/인출/냉각 조건을 변수로 다룬다. 구멍이 1.75mm라고 냉각 후 직경이 자동으로 같아진다고 가정하지 않는다.
- 얇은 구간·기포·오염·타원도까지 자동 복원된다는 주장은 금지한다. 재가열 자체가 무조건 해롭거나 유익하다고도 단정하지 않는다. 수지 등급·건조·체류·열이력을 기록한다.
- 현재는 미검증 가설이다. 사용자 원영상이 확보되면 그 공정을 다시 분류하되 연구 전체를 멈추지 않는다.

C. 동일 하드웨어의 정속/수동 측정 운전
- 별도 폐기형 MVP가 아니라 A의 기본 운전 모드다. 센서 피드백의 품질·폐기율 개선이 추가 BOM보다 유리한지 같은 원료/목표속도로 비교한다.
- 센서 고장 때 계속 정상 생산으로 처리하는 대체 운전은 아니다. 계측 불가 구간은 격리/미확인으로 기록한다.

PET병 스트립 전용기, 고가 레이저 게이지/멜트펌프/진공 정형은 범위·가격 비교 대상이다. 원료 범위를 포기하거나 고가 보조장치를 기본 구매하는 선택은 하지 않는다.

## 4. 간단하지만 제품과 연결된 모델
냉각 후 고체 단면에 대해 질량수지:
mdot = rho_s * A_final * v_line
원형 근사: d_final = sqrt(4 * mdot / (pi * rho_s * v_line))
타원 근사: A_final = pi * dx * dy / 4.
이 관계는 유량·선속도가 흔들리면 최종 직경도 바뀐다는 뜻이며 노즐 보어만으로 최종 직경을 정할 수 없음을 보여준다. rho_s는 냉각 후 밀도다. 용융 체적유량과 혼용하지 않는다.
열/점도/다이 출구 변형/냉각 수축은 별도 불확실성으로 둔다. 알려지지 않은 값을 맞춰서 가상 합격을 만들지 않는다.
실제 다이 출구 x540→게이지 x809의 269mm가 피드백 사장거리다(PLA 100g/h·9.313mm/s 가정 시 약 28.9초). 게이지→니프 x829의 20mm는 이미 형성된 재료의 수송거리이지 제어계 입력 지연을 대신하지 않는다. 모터 응답·미끄럼·결측을 분리한다.
3구역 100W 밴드는 30초 슬롯에서 1기만 요구하고 60W 다이 카트리지와 온도·유량 민감도를 함께 스크리닝한다. 이 슬롯의 접점 수명과 교란 열회복은 미검증. 스풀 모터-샤프트-마찰 클러치-플랜지/드럼의 실제 토크·축방향 예압은 선정 전이며, 샤프트 홈·분할 링·와셔의 공칭 형상 접촉은 토크 정격 증거가 아니다.
Isaac은 제품 운동/공간/재료 이송에, 간단한 별도 공정 모델은 온도/유량/직경 제어에 사용한다. 이 모델이 실제 용융 FEM/CFD 해석이나 재료시험인 척하지 않는다.

## 5. 품질 측정과 가상시험의 경계
- 냉각·인출 후 상태의 1.75±0.05mm를 기본 목표로 한다. 평균만 보지 않고 각 측정축, 길이별 이탈·최대값·규격 내 길이, startup/reject/미관측 길이를 분리한다.
- dx/dy 두 축의 차이는 타원도 지표이지 임의 방향의 최대 타원도를 완전히 찾는 값은 아니다. 회전/다방향 표본 마이크로미터 대조를 후속 물리시험에 넣는다.
- 센서는 해상도와 정확도를 분리한다. 실제 기준물/마이크로미터 보정과 왕복 오차·온도 드리프트·스프링 접촉 변형을 검토한다. 초기 계측 불확실성 목표 U95<=0.01mm는 설계 가정이며 현재 성능 주장이 아니다.
- 원료별 건조/보관, 이물 선별, 기포·표면·취성, 필라멘트 질량/길이와 인출성을 함께 본다. PET!=PETG, TPU에는 압착·신장 영향이 크므로 원료별 제어 조건을 둔다.
- 가상시험: 공급 유량 변화, 온도 회복/냉각 변화, 센서 바이어스/누락, 풀러 슬립, 스풀 반경·장력 변화, 필터 막힘 신호, 500W 동시 수요를 넣고 정속 기준과 피드백을 비교한다.
- 미보정 모델의 규격 내 예측과 실제 규격 내 연속 길이는 다른 결과다. 실제 물리 출력을 이번 문서 변경으로 주장하지 않는다.

## 6. 경제성 및 다음 작업
목적은 처리량 최대화가 아니라 확보 가능한 품질에서 유효 생산량 대비 전체 비용을 낮추는 것이다. 후보별 추가 BOM/배송/가공, 규격 내 수율, 재작업/폐기, 에너지, 재료별 적용범위를 나란히 둔다. 수명·시간단가가 없으면 임의 상각비를 확정하지 않는다. 단품 광고가를 배송·가공 포함 시스템 견적으로 바꾸지 않는다.
현재 사용자가 재확인한 자산은 **2NC 비상정지 버튼 1개, 기존 Anycubic Chiron 도너 프린터와 그 PSU**다. 사용자가 도너 PSU를 **24V 800W, 외형 240×120×65mm**로, 보유 2NC 버튼을 **35×35mm**로 보고했다. 이는 명판 사진·독립 실측·장착구멍·전기적 정격/보호 또는 버튼 35×35mm의 대상 부위(헤드/몸체/패널)를 확인한 증거가 아니다. `validation/physical_v08/inventory_confirmation.csv`의 2020/2040 길이도 실측 재고가 아니다. 같은 치수의 현행 PSU CAD 상자와 500W 운전 상한은 장착/냉각/전원 적합성을 보장하지 않는다. 버튼의 모델·접점 정격·강제개리·독립 하드컷 회로도 미확인이다. 기존 Chiron의 프레임 프로파일, 가이드, 스테퍼, 팬/히터/센서 등은 가능한 재사용 *대상*이지만 각각 길이·치수·신호(STEP/DIR 스테퍼를 PWM/DIR 풀러/권취로 간주 금지)·내열/전류·상태를 확인하기 전에는 현행 적격 BOM 재고로 배정하지 않는다. 원본의 과거 PLA/ABS 필라멘트 기록은 별도 기준 원료 펠릿의 보유 근거가 아니다. C1 인계의 '보유·0원' 나머지 9행은 자동으로 0원 처리하지 않는다. 활성 `system_bom.csv` 210행은 모두 착지가격 미견적(버튼/PSU 2행은 재구매 불요 *조건부*, 사용 적격 HOLD)이고 총비용은 미정이다. 과거 모터 후보 110,200원은 100,000원 전체 soft limit 대비 그 후보 하나만 10,200원 높다. 동일 최종 제품의 기준 펠릿 입력→압출→조절 냉각→직교 직경 계측→인출→장력 분리 권취를 먼저 검증하고 S1/S2 연결을 병행하되, 단계 구매가 전체비용 절감이나 안전부품 생략을 뜻하지 않는다.
기존 95,000원 PSU + 15,000원 DECA 버튼 + 게시 배송5,500원 = 115,500원은 **현재 보유한 둘을 다시 산다는 미선정 과거 바스켓**이므로 신규 제작비나 초과액이 아니다. 도너 PSU가 명판·외형·보호·부하 적합성을 만족할 때 신규 PSU 구매는 필요 없다. 다음 대체 PSU 후보는 도너 부적합 판정 때만 비교한다: [JMDISPLAY](https://crpkrjang.cafe24.com/product/smps-12v24v-800w-%EC%82%B0%EC%97%85%EC%9A%A9-%EC%A0%84%EC%9B%90%EA%B3%B5%EA%B8%B0/65/) 표시가95,000원(+게시 배송2,500원)은 24V 옵션별 가격·외형·정격 미확인이다. AliExpress [S-800-24](https://www.aliexpress.com/item/33059280218.html)의 첫 표시58,000원은 **기본 110V 선택**이며 한국용 220V+24V 조합 가격·배송 미확인; 제목 24V 33A는 산술상792W로 800W 계약과 차이가 있다. [다른 S-800-24 판매자](https://yqmskj.en.made-in-china.com/product/fOqtDjJHaThR/China-S-800-24-800W-24VDC-33A-AC-DC-Switching-Power-Supply-Unit.html)는 291×132×68mm/최소10개/US$2.50–400 범위, [HX-800-24](https://www.huyssenpsu.com/psu-dc-24v-800w-switch-mode-power-supply-hx-800-24-product/)는 240×125×65mm로 현행 포락선을 벗어난다. 표시가로 외형·인증·500W 운전·독립 보호를 완화하지 않는다. [DECA 2NC](https://parts-parts.co.kr/product/pp-b321-22%ED%8C%8C%EC%9D%B4-%EB%B9%84%EC%83%81%EC%8A%A4%EC%9C%84%EC%B9%98%EB%B9%84%EC%83%81%EC%A0%95%EC%A7%80%EB%AA%85%ED%8C%902nc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)도 보유 버튼과 다른 *대체* 후보이고 접촉기·인터록·퓨즈 비용은 별도 미견적이다.

| Chiron 도너 자산 | 동일 제품의 재사용 목표 | 비용 반영 전 확인 |
|---|---|---|
| 24V PSU | 기존 전원 베이에 장착해 500W 단계 부하 공급 | 명판/전류/입력전압·접지·보호·실측 치수·상태; 부적격이면 대체 구매 견적 |
| 2020/2040 알루미늄 프로파일 | 현행 프레임 `FR-*` 절단표에 재활용 | `bom/profile_cut_plan.csv`의 공칭 원봉 투입 2020 4,530mm/2040 3,680mm(각각 절단 후 3,380/2,700mm + 커프/잔량)를 길이·단면·슬롯 규격·손상 실측과 개별 절단 배치로 대조; 과거 다른 설계의 2040 2,180mm 기록으로 대체 금지 |
| 스테퍼·드라이버·가이드/베어링·팬 | 축/이송/지지/냉각 후보 | 명판·축/커플링·구동 신호·연속 토크/열·유량/고정 치수 및 상태; M1/M2·PWM/DIR 풀러/권취 적격 자동 가정 금지 |
| 핫엔드·베드/히터/센서 | 압출 열구역·온도 계측의 부품 후보 | 현행 다이/배럴의 열용량·가열 면적·정격·단열·보호/퓨즈 경로가 다르므로 출력·온도 표시만으로 전용 금지 |

동일 하류의 저비용 **기준 원료 구매 후보**는 [태강 PLA 펠릿 1kg](https://3dprinterstore.co.kr/product/%ED%83%9C%EA%B0%95-pla-%ED%8E%A0%EB%A6%BF-pellet/738/) 표시가11,000원/게시 국내배송4,000원(합계 조건부15,000원): 판매자는 NatureWorks 원료를 말하지만 등급·로트·수분/건조·MFI·입도는 미제시. [ARTME Ingeo 4043D](https://artme-3d.shop/products/pla-pellets) 0.5kg은 €5.04, [전세계 2kg 이하 배송](https://artme-3d.shop/policies/shipping-policy)은 €25 게시값이라 다른 통화·중량의 국내 원료와 단가만 비교할 수 없다. PLA로 하류 형성 경로를 검증해도 폐출력물·purge 원료의 품질 성공은 아니다. AliExpress [24V 200W 모터 후보](https://www.aliexpress.com/item/32899600460.html)는 제목만 확인했으며 옵션별 모터+드라이버 가격·축/정격토크·감속·배송 미확인, M1 선정 아님. [기계식 필라멘트 존재 센서](https://www.aliexpress.com/item/32819132939.html)는 직경 측정기가 아니므로 2축 품질 게이지 대안에서 제외한다. 공급사 RFQ는 동일 정격/외형·안전 검증·한국 착지가격·반품/고장 위험을 포함한다. 사용자가 선택한 방향은 **전체 견적 후 예산 협의**이며 현재의 추가 비용/주문 승인은 아니다. 부품·원료 후보 경계는 `c2.1/bom/quality_component_candidates.csv`에 둔다.

기준 원료는 **견적만 준비하고 주문하지 않는다**. 판매자 페이지의 1kg 태강 PLA 11,000원과 국내 기본 택배 4,000원을 더한 **조건부 15,000원**은 도서·산간 추가금/재고·결제/건조 비용을 뺀 공개 금액이다. ARTME 4043D는 수지 등급을 명시하지만 로트는 미제시다. 0.5kg **€5.04 + 전세계 2kg 이하 게시 배송 €25 = 조건부 €30.04**는 한국 배송 옵션/포장 중량·세금·환율을 확인하지 않은 금액이다. 중량·통화·등급이 달라 최저 착지가격을 확정하지 않는다. 두 후보 모두 건조 조건/수분과 입도·MFI·품질 측정용 기준물, 연속 운전·시작 폐기 길이 및 안전 승인 없이 시험 원료로 선정하지 않는다.

다음 구현의 주축은 최종 압출 모듈의 실제 다이/열구역/냉각 길이/센서 설치/풀러/장력 분리, 직경 계측 인터페이스와 제어 코드, 동일 제품 공정 모델이다. 버퍼와 교체 장착하는 서비스 입력은 동일 조립 설계의 CAD 형상이지 이미 보유한 부품이나 공급된 기준 원료가 아니다. 원료 확보·건조 기준 및 별도 물리 시험 승인 전까지 디지털 비교만 가능하다. 동시에 상류 수신 입도·수분·공급률을 하류 요구에서 정하고 이송계를 단순화한다.
도면/코드/시험은 선정된 전체 조립체에 재통합한다. 대규모 독립 물성/solver 연구, 새로운 승인 phase, 근거 없는 후보 증식은 하지 않는다. 상류 연결 실패, 물리 실험, 구매·통전·병합은 기존 경계를 유지한다.

## 7. 같은 제품의 기준 원료 모델·제어·비용 비교 (VP1)
실행 근거: `c2.1/results/downstream_route_comparison.json`, `c2.1/results/power_sim.json`, `c2.1/results/firmware_build.json`, `c2.1/bom/quality_component_candidates.csv`. 아래는 모두 **미보정 가상 민감도**이며 실제 필라멘트 성능·수율 또는 물리 제작 승인 결과가 아니다. PLA 고체 밀도 1240 kg/m³, 기준 유량 100g/h(스크루 실측 없음), 1.75mm 원형 단면이면 목표 선속 9.313mm/s. 269mm 다이→게이지 약 28.9초, 20mm 게이지→니프 약 2.1초; 열전도·대류·클러치 토크·재질별 온도 목표는 모델 가정이다. 압출 압력/팽창/기포·표면·열이력·실제 센서 오차는 미구현.

| PLA 240초 조건 | C 정속 규격 내/니프 도달 길이 | A 직경 피드백 규격 내/니프 도달 길이 | 해석 |
|---|---:|---:|---|
| 유량 변동(+35%, -29%), +15µm 센서 편향, 외기+8°C/배럴 추가손실25W, 8초 계측 결측·클러치 고장 | 1,591.67/1,938.13mm (82.12%) | 835.73/1,100.30mm (75.95%); 계측 결측 후 146.0초에 품질 HOLD | A는 멈춰 생산 길이가 다르다. 같은 시간에서 A가 수율을 개선했다는 결론 금지; 미측정/미냉각/대기 재료 격리 |
| 유량 +20% 지속 | 0/1,945.58mm | 1,401.48/2,247.74mm (62.35%) | **가정된 센서 영점/냉각 아래에서만** 지속 오프셋 보정 가능성 |
| 별도 권취 클러치 고장(170..178초, 장력 10N) | 1,871.07/1,938.13mm (96.54%) | 1,877.34/1,944.49mm (96.55%) | 가정된 그립 임계 8N을 넘으면 양쪽 모두 약 67mm가 규격 밖이다. 이 차이만으로 피드백의 우월성을 주장하지 않는다. |
| 직교 게이지 한 축만 145..153초 명시적 불량 | 1,871.07/1,945.58mm (96.17%); 미계측 74.51mm | 1,062.34/1,062.34mm (니프 도달분만 100%); 145.0초 중단, 미확인 잔류 289.05mm, 전체 생성 1,351.39mm 중 확인 비율 78.61% | 한 축만 살아 있어도 2축 품질 판정/피드백은 성립하지 않는다. A의 니프 도달분 100%를 전체 생산 수율로 해석 금지 |

90초 정상 가상 운전의 니프 도달 부분은 C/A 모두 규격 내지만, 각각 약 290mm는 종단에서 다이→니프 사이에 남아 미확인으로 차감된다. C에도 사후 평가용 같은 2축 센서 신호를 가정하되 제어에는 사용하지 않았다. 가상 모델이 과거에는 **참 직경 2축만** 규격 안이면 편향 게이지가 범위 밖으로 표시해도 합격 길이로 셌다. 100g/h·70초·고정속도 PLA에서 참 직경 1.75mm, 양 계측축 1.85mm(+0.10mm 편향)의 니프 도달 362.29mm 전량이 잘못 합격했으나, 현행 판정은 참 직경 두 축과 측정 두 축이 모두 1.70..1.80mm·축차≤0.05mm이며 냉각 완료일 때만 인정해 이 경우 0mm다. PI 입력은 두 계측축의 면적등가 직경으로 C++ `controller_core.cpp` 커널을 호출한다. 모델의 `sensor_dropout`은 새 표본 없음으로 취급해 운전 중 1초 초과 시 중단하고, `sensor_major_dropout`/`sensor_minor_dropout`은 명시적 불량 축으로 취급해 첫 운전 중 불량 입력에 즉시 중단한다. 기존 40..40.4초 단일축 불량을 1초 표본 부재로 뭉뚱그리면 끝까지 운전했지만 현행 모델은 40.0초에 중단한다. 펌웨어는 운전 중 불량 축/오래된 표본을 `quality_hold`에 래치하고 수동 리셋 전 자동 재기동을 거부한다. 가상 모델은 펌웨어 전체 I/O·보호/전력 배분 실행이나 실제 재기동 잔재를 재현하지 않는다. 단면 두 축 계측만으로 최대 타원도나 교정 정확도를 증명하지 않는다.

실제 2축 센서 인터페이스는 미구현이다. 한 축 불량을 C++ 입력의 `gauge_valid=false`로 전달한다는 계약이 충족되어야 위의 즉시 HOLD와 같아지며, 센서 드라이버·배선·실물 안전회로의 연동은 별도 검증 전까지 HOLD다.

기존 복합 교란의 클러치 고장은 170..178초이나 피드백 A는 계측 누락으로 146초에 이미 정지하므로 그 실행에서 피드백의 권취 고장 반응을 시험했다고 주장할 수 없다. 별도 `clutch_fault` 실행은 같은 8초 고장을 결측 없이 양쪽 경로에 적용했다. 위의 규격 내 길이는 니프 도달 모델 결과이며 종단에 남은 약 290mm는 미확인으로 제외한다. 70Nmm 클러치, 8N 인출 그립 경계 및 초과 장력에 대한 슬립률은 선정/교정된 실제 값이 아니다.

권취 반경은 처음부터 다이 생성 길이를 누적하던 모델 오류를 고쳐 **니프 도달 길이만** 누적한다. 이전에는 첫 10초 동안 니프에 닿은 필라멘트가 0mm인데도 반경이 35.0000→35.0229mm로 증가했다. 수정된 90초 PLA 정속 가상 운전에서는 첫 니프 도달 31.1초의 반경 35.0000mm, 마지막 니프 도달 시 35.1359mm이고 종단의 미확인 다이→니프 잔류 289.65mm는 권취량에 넣지 않는다. 니프 도달을 권취의 근사로 쓰므로 실제 니프→스풀 이동거리·시동 폐기/분리·스풀 가속과 권취 토크는 여전히 미검증이다.

냉각 민감도: 가정한 유효 강제대류 길이 250mm일 때 PLA 2팬 게이지 중심 53.80°C(가정 준비 한계55°C, 여유1.20°C), 3팬 44.64°C. TPU 2팬 60.28°C(가정 한계50°C, 불합격), 3팬 48.46°C(여유1.54°C). PET는 같은 모델 2팬 45.89°C, 3팬 39.14°C. 팬의 압력-유량·공기 흐름·수지 물성과 광학/접촉계측 편향은 측정하지 않았다. 기존 남쪽 팬 두 대의 막힌 트레이 벽에 78×21mm 창 두 개, 가동 후드 상부에 Ø70 관통구와 분리형 80×80×38mm 팬 참조를 추가해 **공기 통로만** 형상 검증했다. 100mm 후드 이동이 가정한 50..250mm 유효 대류 길이를 구현한다는 증거는 없다.

인출 롤러가 원래 필라멘트 y275의 *끝면*에 닿던 결함을 수정해 22mm 폭 중앙(y264..286)에 선을 놓고 양쪽 롤러의 1.75mm 접촉과 베어링 보어/정지좌 무간섭을 BRep으로 확인했다. 마찰력·TPU 찌그러짐·스프링 압력은 미검증. 권취 샤프트의 헐거운 드럼 보어는 구동이 아니므로 키드 칼라→스프링 자리→마찰 패드→플랜지 경로를 별도 CAD로 배치했다. 기존 형상은 플랜지가 오른쪽으로 3mm 이동해도 샤프트·베어링·클러치에 BRep 접촉이 없었다. 초기 Ø14.4 홈뿌리/Ø24 분할 링 후보는 시판품 치수와 불일치했다. 현행 디지털 후보는 Ø16 샤프트 y96..97/y168..169의 폭1mm·Ø15.02 홈과 ES-16 공칭 링 외형 포락선(2회 감김 실제 형상 아님), 오른쪽 플랜지 y167..168의 Ø30/Ø16.2 와셔다. 오른쪽으로 밀린 플랜지→와셔→링→샤프트의 이탈 정지 경로만 형상으로 확인했고, 링과 칼라/와셔 사이에는 공칭 면간격이 있다. 클러치 예압·토크·70Nmm 가상 모델값/반경별 약2N 장력은 실제 정격이 아니다.
추가로 이전 `PULL_ROLLER_ADJ`는 롤러·캐리지·횡방향(Y축) 스프링/포스트를 하나의 강체로 융합한 CAD였다. 위의 정지좌 필라멘트 교차는 니프의 수직 순응이나 독립 회전을 증명하지 못했다. 현행 후보는 Ø20 아이들러+Ø6 축을 별도 회전체로 분리하고, 두 Ø6.04 베어링 보어 포락선의 `PULL_IDLER_CARRIAGE`가 프레임의 Ø5 수직 가이드 두 곳을 따라 1.5mm 움직인다. 하부/상부 금속 정지좌가 니프 1.5..3.0mm를 제한하고 두 `PULL_IDLER_SPRINGS`의 축방향 **공간 포락선**은 그 사이 설치 높이 8.5→7.0mm를 나타낸다. 공칭 축-보어 반경 간격 0.02mm도 공차·부싱/베어링·런아웃을 제외한 CAD 간격일 뿐, 교정된 필라멘트 허용 편차나 회전 수명 근거가 아니다. 니프 세 위치(최소/공칭 필라멘트/최대)에서 회전체·캐리지·스프링·프레임/정지좌 BRep 무간섭 및 분리 회전 경로만 확인했다. 30N 아이들러 축 굽힘은 가상 하중 감도 분석이고 실제 스프링 자유/솔리드 높이·예압·접촉력·TPU 압착·풀러 미끄럼과 실제 축추력·체결/비용은 **미선정/미검증**이다. `winder_geometry.json`의 `geometry_passed`와 `path_check.json`의 `all_nip_geometry_clear`는 물리 니프 그립 합격이 아니다.
초기 분리안은 새 캐리지/정지좌/축이 미선정 풀러 모터의 y232..248 Ø16 노즈와 1.77..54.61mm³ 범위로 겹쳤다(위치별 BRep). 축/캐리지의 첫 면을 y249로 물리고 프레임 옆판을 y259..263/y287..291로 조정하여 회전체 y264..286와 양쪽 1mm, 모터 노즈 끝 y248와 이동축 시작 y249 사이 **공칭 1mm** 간격을 확보했다. 이 역시 실제 모터축/벨트·마운트/공차/편심을 포함하지 않는 후보 간격이다.
USD에는 이 스프링 공간 두 곳을 **시각 전용/충돌 비활성** 형상으로 남긴다. 선택된 실제 스프링이 없으므로 `materials.py`에서 공칭 질량 0/강재 포락선 질량 상한으로 분리한다. 이는 구매비·실제 질량 0원/0g을 뜻하지 않으며, 부품표의 스프링 2개는 `UNQUOTED_NOT_ZERO`다. 모터·베어링·스프링 선정 후 CAD/질량/간섭을 다시 산정해야 한다.

ES-16 제조사 명세[S7]: 홈 Ø15.02±0.075mm, 폭1.00+0.08/−0.00mm, 링 축두께0.89±0.05mm, 반경 방향 벽1.40+0.08/−0.13mm, 자유 상태 내경14.90+0/−0.33mm. 설치 링의 단순 환형 외경 공칭 약17.82mm이므로 초기 Ø24 보유력 모델을 폐기했다. 홈-링 축유격은 **한쪽 0.06..0.24mm, 두 곳 합계 최악 0.48mm**(다른 축 스택 공차·열팽창·탄성은 제외). 와셔의 Ø16.2 공칭 보어와 링 최소 외반경8.7425mm에서 와셔 편심0.1mm를 *가정*한 반경 겹침 하한0.5425mm는 와셔 보어/샤프트 제작 공차가 빠진 조건부 기하 스크리닝이지 압력면·하중 정격이 아니다. 제조사 홈 항복3820N은 홈 재질 항복45,000psi/안전계수2 조건, 링 전단14,900N은 안전계수3 조건이며 PPR 재질·축피로·조립/베어링·반복 슬립이 검증되지 않아 적용하지 않는다. 링 MPN은 **치수 참조**일 뿐 선정/견적/주문이 아니다.
SSB-0087[S8]은 Ø16.46 축을 피하지만 공표 하중62.3N의 **작업 높이1.57mm**는 현행 미선정 스프링 자리1.00mm보다 **0.57mm 크다**. 1mm로 압축 가능한지, 솔리드 높이·영구변형·하중은 해당 자료에서 확인하지 못했다. 이 스프링을 CAD에 끼워 넣거나 62.3N을 예압으로 채택하지 않았다. 홈 유격까지 고려한 스프링 길이 조정·마찰계수/토크 측정과 washer/링/홈 공차·피로·베어링 축추력 평가 없이 권취 운전 HOLD. 두 공급품 모두 착지·가공 단가 미확인이라 0원 처리하지 않으며, 최소 기능 비용안도 미확정이다. 근거 화면 `c2.1/results/winder_geometry.json`의 `retention_fit_screen`; 업체 카탈로그값과 가상 CAD를 물리시험으로 오인하지 않는다.
권취 조립의 제작 경로 점검에서 기존 베어링 좌석(x688..712)과 모터(x680..720)가 프레임 최대 x630 밖에 떠 있는 결함을 발견했다. 같은 제품의 `WIND_MOUNT`는 앞쪽 알루미늄 20mm 직립재의 y60면에 Ø5.5 관통 후보 구멍 두 개로 닿고, 플랜지 회전면 바깥(x590..600)을 경유하는 두 강재 레일이 양쪽 베어링 바닥에, 별도 하부 받침이 모터 바닥에 접한다. CAD의 면 접촉·간섭 부재는 실제 볼트 체결·모터 선정·피로/진동 강도 증명이 아니다. 도너 프로파일 또는 부족분 신규 조달재의 슬롯/웹과 볼트·용접·베어링 사양을 확정하기 전 가공/권취 운전 승인 HOLD. 드럼은 과거 Ø70 외경-Ø17 내경의 거의 실심 강재 링(약 1,649g) 대신 2mm 강관과 두 3mm 내부 허브 웹(약 345g)으로 형상을 바로잡았다. 후보 강재 밀도 7.85g/cm³로 두 3mm 플랜지 포함 회전 스풀은 3,117.86→1,813.98g(-1,303.88g, 약 -41.8%), 정지 강재 마운트는 약 0.30kg 추가다(`c2.1/results/winder_geometry.json`). 이 수치에는 권취 필라멘트, 모터·체결재·용접 비드, 실제 재료/공정 손실이 없으며 질량 절감이 제조 단가 절감을 뜻하지 않는다. BOM의 마운트/웹 제작·구매·배송은 미견적이고 모터 한 후보 110,200원은 이미 전체 100,000원 soft limit를 초과한다. 적재·강성·허용 편심과 정지/시동 클러치 토크·방호는 여전히 선정/실측 대상이다.
인출 프레임도 기존에는 x822..846으로 끝나는 냉각 트레이 x820과 2mm 이상 떨어져 있고 트레이 자체도 후면 프레임 y360에서 끝나는 판재 y315까지 간격이 있어 하중 경로가 없었다. `PULL_COOL_MOUNT` 후보는 후면 Al 직립재 x630면의 Ø5.5 후보 구멍 네 개→20×20×2mm 강재 사각관 x634..836→18×16×2mm 인출 받침관 x824..842의 연속 금속 경로로 프레임 바닥 z100에 닿는다. 별도 강재 받침 x545..820, y300..315, z95..103은 2mm 냉각 트레이 바닥에 면접촉한다. 풀러 프레임과 받침에는 동일한 Ø4.5 관통 후보 구멍 두 개를 배치했다. 롤러 하부와 0.25mm 밖에 떨어지지 않아 볼트 머리는 면 아래에 매입해야 하나 실제 체결재는 미선정이다. 이 후보 랙은 밀도 7.85g/cm³ 가정 시 약 0.707kg의 추가 정지 강재; 권취 마운트 약 0.295kg과 합산 약 1.002kg이고, 스풀 회전 질량 절감 1.304kg과 상쇄해 원가 우위로 해석하지 않는다. 프로파일 슬롯, 실제 냉각 트레이/팬·계측계 체결, 용접/체결 토크, 장거리 캔틸레버의 동적 강성과 제작비는 별도 HOLD다. 랙 형상 접촉·간섭 시험은 가공 허가가 아니다.

전력은 M1 196.8W, M2 43.2W, 3팬 24W가 **미선정/추정**, 히터 단일 밴드100W + 다이60W가 이름표 기초다. 전체 동시 기준부하 424W이며, 500W 상한에서 풀러+권취+부가 구동에 히터를 유지하려면 최대 76W만 남는다. `power_sim.py`의 444W 피크는 임의 **20W 보조부하 시험 입력**을 더한 값이고 실제 정격/구매안이 아니다. 보조부하 미확인 또는 상한 거부 시 호스트 컨트롤러 M2를 정지시킨다. 150W를 주면 밴드가 거부되어 열회복을 보장할 수 없다. 30초 슬롯·보호 릴레이 선정/온도 회복은 별도 시험 HOLD.

센서/품질 비용 후보(판매자 공개 단가, 2026-09-27 조회; 배송/부가세/관세/가공/보정·환율/착지가격은 미견적): Hall 레버 2축안은 Adafruit TMAG5273A1 보드 두 개 $11.90 **전자부품만**; 출구 형상에 넣은 혼합 1 Hall+1 광학안도 두 축 모두 교정 전 HOLD. TSL1401CL 광학 2축안의 모듈 두 개 R1,350(현지 세전), 128픽셀/8.12mm ⇒ 센서면 피치 약0.0634mm로 물체면 정확도 주장이 불가하다. 1.75mm 단일 기준핀 £14.712001와 Fowler 마이크로미터 $52도 각 판매자 공개 단가일 뿐이며 추가 기준핀/교정증명 미포함이다. 나열한 통화는 서로 합산하지 않는다. 미보유 모터 후보만 110,200원으로 이미 10만원 soft limit 초과; 추가 센서·구동·배송비를 0원으로 넣을 수 없다. 센서 없는 C가 낮은 초기비용이지만 편차 때 0mm인 모델 사례와 결측 중단 사례를 함께 보고 **정확도·착지가격·실제 길이당 품질 손실**이 얻어질 때만 A/센서 구성을 선택한다. 품절 RC 슬리퍼 클러치 £15.95는 전용 연속슬립 토크 정격이 없어 견적 근거에서 제외한다.

재가열 정형 패스 B는 압력·온도·열이력·형상 및 추가전력이 없어 **비순위 HOLD**. 보어가 1.75mm라서 결핍/기포를 메운다는 허구의 직경 배율을 삭제했다. 상류 수용 유량 100g/h는 원료 공급·스크루 실측 전 설계 목표, 허용 입도/건조 수분은 등급별 투입구·멜트 필터·압력/기포 시험 없이 4mm/200ppm으로 확정하지 않는다.

## 8. 상류 인계의 하류 기준과 검증 경계
단축 압출기 100g/h 설계 목표에서 **정속·동일 밀도·원형/무기포**만 가정하면 유량 변화에 따른 직경 1.70..1.80mm 창은 공칭 대비 약 -5.63..+5.80%다. 269mm 피드백 사장시간 동안 기준 유량에 해당하는 질량은 약 0.802g이며, 이는 **버퍼 최소 용량 설계 또는 실제 허용 요동 폭을 증명하지 않는다**. 순간 공급 중단·혼합재·스크루 압력/다이 온도·기포·편심은 추가 결함을 만든다. 원료 혼합 대신 재질/등급/열이력별 건조와 체과, 이물 제거·전달 유량·버퍼 질량 변동을 측정한다. S2 화면 nominal Ø4/스크루 채널 치수만으로 통과 플레이크의 장경·압출 적합성·200ppm 수분을 확정하지 않는다.

이전 국부시험의 STEP `875551dd…`에서는 S1 하부 통과 22개 중 메인 스크루 픽업 10, 전진 1, 실제 S2 입구 0; 좁힌 `chute_inlet`은 22개 중 입구 경로 2, 실제 S2 입구 0이었다. 이 USD는 당시 STEP에서 변환됐으며 현행 VP1 형상과 해시가 맞지 않았다. 새 형상은 `chute.py`에서 측면 이송 스크루 스윕 반경 6.7→7.2mm를 증대하고 바닥 금속을 **국소 릴리프**하여 x223/z336.5 부근 정체 Ø3mm 포락선에 닿게 했다. 정적 BRep·단위시험의 무간섭과 인계 접근성은 축 토크·실제 플레이크 픽업을 입증하지 않는다. 사용자는 NVIDIA EULA 수락을 명시했다.

현행 STEP SHA256 `c3620578…`/USDA `d528db25…`를 연결한 Isaac Sim headless `verify_full.py --steps 12800 --dt 0.005 --cycles 8 --probes 200` 결과는 구동 비율 추적 통과, S1 출구 115/200·스크루 픽업 33/200, **S2 실제 입구/같은 스크린 보어/버퍼 모두 0/200**의 `LOCALIZED_BLOCKED`다. 대용량 원시 출력의 경로/SHA256과 실행 인자는 `c2.2/results/full_machine/selected_connected_flow_summary.json`에 기록한다. 별도 22개씩 주입한 `flow_localize/results.json`은 S1 배출에서 픽업11·전진5·S2 입구0, 슈트 단독 주입에서 x335 통과4·실제 S2 입구0, S2 단독 주입에서 보어→버퍼3을 기록했다. 이 수치들은 서로 다른 주입 집단이므로 통과율을 곱하거나 연결 성공으로 만들지 않는다. 슈트 경로 말단·+Y 입구 인계 실패를 우선 결함으로 유지한다. 접촉 이벤트 스트림 0은 무접촉 증거가 아니며 최종 scene-query 근접부품은 충격력 기록이 아니다. 압출 유량 안정성과 폐원료에서의 규격 내 필라멘트 생산은 여전히 HOLD.

현행 형상을 유지한 체류시간 분리 시험: `flow_localize/phase_chute_inlet.json`은 같은 STEP `c3620578…`/USDA `d528db25…`, Ø3mm 구형 22개, dt=0.0025초·24,000스텝·M1 5사이클(60초)에서 x335 통과4/22, 실제 +Y S2 입구0/22였다. 동일 주입·장면·dt를 38,400스텝·8사이클(96초)로 연장한 별도 Isaac native 결과는 x335 통과6/22, 그 뒤 입구 전 월드/공정 손실5개, 실제 S2 입구0/22다. 연장 실행 인자·원시 출력 해시·대표 궤적은 `c2.2/results/full_machine/flow_localize/selected_chute_residence_summary.json`에 고정했다. 96초 실행에서 한 입자는 (x,y,z)=(345.0,231.9,339.2)→(359.1,232.5,319.1)mm로 하강했다. 일부 y255 평면 교차는 x392..396,z−14..22mm에서 발생하여 출구가 아니다. 긴 체류만으로 실제 인계가 성립하지 않았다.

그 하강과 대조한 현행 CAD의 **확인된 형상 결함**: `chute.py:897`의 공칭 `outlet` 바닥 x350..359.7,y250.3..258,z311.8..317.3 상자 모서리의 S2 회전축 (308.5694647,280) 기준 최대 반경은 63.290mm다. 같은 함수의 y234..260, 반경63.5mm `rotor_clearance` 절삭 안에 상자 전체가 들어가므로 STEP에 이 바닥은 남지 않는다. 외측 `shelf`/볼은 일부 남지만 출구 중앙의 연속 받침으로 간주할 수 없다. `machine_integration.json`의 현재 정격 아닌 기하 경계는 로터 반경62.0mm, 넓은 수신 날 끝 y234.671<커플링 웹 시작 y235.0(여유0.329mm), 좁은 동력 꼬리 날의 연속 반경 여유0.59mm(기존 보수 합격 경계0.5mm), 고정 셸 반경 여유1.5mm다. 넓은 날을 연장하거나 꼬리 날을 넓히는 국소 수정은 현행 로터 무간섭 경계를 거의 소진하고, 바닥 상자만 높여도 절삭에 다시 제거된다. **원인 추론**은 회전 날에서 바닥 지지·+Y 추진으로 넘어가는 경로의 단절이며 접촉력/플레이크 거동을 직접 계측한 결론은 아니다. 이 영역의 빠른 국소 패치 대신 회전체·고정 셸·수신구를 함께 재배치/재설계한 뒤 5° BRep 위상 검사와 연속 간격 경계, 동일 STEP→USDA→native 동일 입자 S1→S2 보어→버퍼 시험을 다시 수행한다. 다른 구조가 불가능하다고 단정하지 않으며 기준 원료 동일 하류의 물리 시험도 별도 승인 전 HOLD다.

## 출처
아래는 2026-09-27 조회한 1차 자료다. 제품 성능/가격은 해당 판매자·저자의 진술이며 PPR 검증값이 아니다.
- [S1] Felfil Spooler+: https://felfil.com/felfil-spooler/
- [S2] Filabot, Better Spooling with the Filameasure: https://www.filabot.com/blogs/news/better-spooling-with-the-filameasure
- [S3] InFiDEL 저자 문서: https://infidel-sensor.readthedocs.io/en/latest/ ; 설계 저장소 https://github.com/drspangle/infidel-sensor
- [S4] Petsiuk & Pearce (2020), Open Source 3-D Filament Diameter Sensor for Recycling, Winding and Additive Manufacturing Machines: https://arxiv.org/abs/2012.00191 ; 저자 프로젝트 https://www.appropedia.org/Open_Source_3-D_Filament_Diameter_Sensor_for_Recycling,_Winding_and_Additive_Manufacturing_Machines ; 설계 https://osf.io/qdvu8/
- [S5] Filastruder 공식 kit/FAQ: https://www.filastruder.com/products/filastruder-kit
- [S6] Recreator3D 공식 프로젝트: https://www.recreator3d.com/
- [S7] Smalley ES-16 external two-turn Spirolox ring 치수/제조사 조건부 하중: https://www.smalley.com/ring/es-16
- [S8] Smalley SSB-0087 shaft-clearing wave spring 치수/작동점: https://www.smalley.com/wave-spring/ssb-0087

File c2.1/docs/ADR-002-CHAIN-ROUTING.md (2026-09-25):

# ADR-002: VP1 체인 경로 vs 동결된 C1 구조물 릴리프 (chain routing reliefs)

- 상태: **채택 (디지털 통합 수준)**. C1 루트 소스는 동결 참조로 유지 — 릴리프는
  `c2.1/src/build_machine_integration.py`이 통합 시점에 적용하고, 결과는
  `c2.1/results/machine_integration.json`의 `vp1_stage3.chain_relief_records`에
  기록된다.
- 배경: Stage 1에서 실제 체인/기어 솔리드가 도입되면서, C1에서는 감사 대상이
  아니었던(유지 부품 간 상속 감사 제외) 접촉이 처음 측정되었다:
  CHAIN-A×S1-ROOF-R(60.4)·S1-STUD(104.7)·DRV-B12(88.8)·DRV-DECK(167.9),
  CHAIN-B×DRV-JACK(850.2)·DRV-DECK(167.7), SH40×DRV-M2(2086.9)·DRV-DECK(774.3×2).

## 옵션

1. **릴리프 포켓(채택)** — 통합 단계에서 레거시 솔리드에 절삭 포켓을 적용.
   포켓 = 접촉 영역 bbox + 마진 1.5 mm, 제거 부피를 기록.
2. **아이들러/체인 재배선** — 동결된 스프라켓 데이텀(X/Z)을 유지한 채 체인 경로를
   바꾸려면 새 스프라켓 인스턴스와 새 체인 평면이 필요해 계약(drive 레이아웃,
   매개변수) 위반. 기각.
3. **신규 부품 이동** — S1 지붕/스터드/베어링 플레이트/잭샤프트/모터 위치 변경은
   C1 동결 참조 위반. 기각 (단, JACK은 예외 처리 아래 참조).

## 결정 (부품별)

| 부품 | 처리 | 근거 |
|---|---|---|
| S1-ROOF-R_001 | 포켓 (체인 랩 채널, 코너 절삭) | 브래킷 코너 제거, 하중 기능 유지 |
| S1-STUD_001 | 트림 (y>350.5 테일 제거) | 벽 간 인장 스팬 y 108..329.6 보존 — 체인이 지나는 y 351.5..359 구간만 절제 |
| DRV-B12_001 | 포켓 (상동 코너) | 베어링 시트(x 74..86) 미접촉 |
| DRV-DECK_001 | 포켓 ×4 (체인 A/B, 40T 기어 원) | 플레이트 절삭 구멍 — 구조 기능 유지 |
| DRV-M2_001 | 포켓 (참조 바디) | M2는 미소유 참조 — 실 모터 장착이 지켜야 할 8 mm 기어 클리어런스 표시 |
| DRV-JACK_001 | **절단 (y 370..378.5), 무커플링** | 체인 B 스트랜드가 샤프트 코어를 관통(축중심에서 4.84 mm 오프셋, 체인 밴드 ±5.5) — 샤프트를 체인 밴드 구간에서 절단. 후단 스텁(y 378.5..408)은 스프라켓·기어 물림 구간 뒤쪽이라 토크를 전달하지 않으며 DRV-B20 베어링에 스페이서로 유지됨. 커플링 슬리브(r ≥ 10.2)는 체인(반경 ≤ 9.7)과는 0.5 mm 이상 이격되지만 SP24-B20 허브(r 20, y 362..372)를 피할 수 없어 기각 |

기각 근거: JACK의 턴다운(직경 축소)은 체인이 축심을 관통하므로 불가(잔여 r ≤0.7);
스터드 절단은 벽 간 스팬 상실. 두 경우 모두 구조적 기능 상실 → 위 표의 방식 채택.

## 증거

- 적용 후 감사: vp1_against_retained/vp1_internal unexpected = 0.
- 남는 접촉은 FUNCTIONAL_PAIRS(저널 끼워맞춤, 기어 물림, 키 조립, 사이클로이드
  링 물림)뿐.
- 제거 부피(mm³)와 포켓 bbox는 `vp1_stage3.chain_relief_records` 참조.

---

## ADDENDUM (2026-09-22, VP1 Stage 4, rev B — SUPERSEDES the rev A decision)

rev A는 "C1 freeze가 구동 배치 자체를 동결한다"는 해석 위에 서 있었다. 이 해석은
기각되었다(사용자 결정: C1 루트 소스만 동결, 통합 빌드의 레거시 인스턴스는
이동/교체 가능). rev A의 기능 파괴적 릴리프 두 건 — DRV-JACK 절단(y 370..378.5,
후단 스텁 무토크)과 DRV-M2 8,336 mm³ 포켓 — 은 체인 B가 잭샤프트 코어를
관통하는 것과 이중 헬리컬 메시(하부 쌍 y 286..311)가 M2 참조 바디에 걸리는
것, 두 레이아웃 결함의 직접 결과였다.

### 결정 (rev B)

1. **체인 B 재배선: 구동 스프로킷을 입력축(80, 374)에서 잭샤프트로 이동.**
   새 인스턴스 `DRV-SP24-B20_002`(24T, 보어 10, 잭 y 373..381)가 체인 B를
   끈다; S2 12T(`DRV-SP12-B12_001`)는 동일 XZ 데이텀에서 y 374..382로 이동.
   체인 평면 y 376..381, 76링크(723.9 mm). 잠깐 — 잭샤프트에서 체인 B가
   접선으로 빠져나가므로 스트랜드가 잭 코어로 "되돌아오지 않는다": rev A의
   관통(코어에서 4.84 mm)은 구동 스프로킷이 입력축에 있었기 때문에 존재했다.
   토크 경로: M1 -> CPL12 -> 15T/40T -> 잭샤프트 -> {체인 A 24/24 -> S1,
   체인 B 24/12 -> S2} — 잭샤프트는 **단일 솔리드** y 240..408으로 복원
   (절단·커플링 슬리브 삭제). 토크와 베어링 반력 경로가 양단 지지로 연속.

2. **이중 메시 삭제 → 단일 15T/40T 메시.** 하부 쌍(SH15R 플립 + SH40L 플립,
   y 286..311)은 M2와 접촉하는 유일한 요소였다. 삭제하면 M2 포켓이 필요
   없어지고(모터 바디 무손상), 측정 감사에서 40L/DECK 포켓도 사라진다.
   단일 메시의 헬리컬 추력 상쇄는 (미선정, HOLD) 실제 모터/기어박스 선택에서
   해결한다. 치수 비율 15/40, 중심거 56.940 불변.

3. **삭제된 인스턴스:** `DRV-SH15R_001`, `DRV_SH40L_lower`,
   `DRV-SP24-B12_001`(보어 6 — 보어 10 드라이버로 대체). 이동 인스턴스:
   `DRV-SP24-B20_001`/`DRV-SP24-B25_001` y 354->352, `DRV-SP12-B12_001`
   y 374 유지(페이스 374..382).

4. **남는 기계가공 릴리프(정상, 기능 보존):** DECK 체인 A/B 랩 채널(각
   ~790 mm³), DECK 40T 팁 원(5,051 mm³), B12 코너(442 mm³, 베어링 시트
   보존), ROOF-R 코너(478 mm³), STUD 테일 트림(y>330.5, 벽간 스팬 보존).
   rev A의 기능 파괴 릴리프(잭 절단, M2 거터)는 존재하지 않는다.

5. **감사 증거(스테이지 4 실행):** 잔여 접촉은 FUNCTIONAL_PAIRS(체인 랩
   물림 4, 키 시트 5)뿐. 문서화된 C1 내부 접촉(이 빌드가 감사하지 않는
   보존-내부 쌍): S1-SYNC_001/002 × S1-BR-CAP_001 685.7 mm³ 각.
   예비 감사(/tmp/layout10.py, 레이아웃 v8): 릴리프 후 unexpected = 0.

### REV B 부록 2 (2026-09-22, Isaac 통합 피드백 2건)

1. **S2 회전 방향(체인 B 잭 구동 → S2Ecc = -0.75 x 입력).** 외부 메시(15/40)가
   부호를 반전하고 개방 체인은 부호를 보존하므로 새 레이아웃의 S2 편심 입력은
   음의 방향으로 회전한다. 음의 방향 전체 q=8 사이클(64 상태, BREP 완전 교차,
   moving-vs-fixed 전 쌍) 감사 결과 **간섭 0건** — S2 서브어셈블리 기하는
   방향 대칭이다(`c2.1/results/s2_negative_sweep.json`, 스크립트
   `c2.1/src/s2_direction_audit.py`). 양의 방향 33-상태 스윕은
   cad_validation.json에 기존 기록. 즉 Isaac에서 보고된 S2Ecc 정지(0.23 rad
   후 err 37.47 rad)는 기하 간섭이 아니라 시뮬레이터 추적 과제(c2.2 재검증)
   이다. 크로스 체인(꼬인 링크)은 제작 불가 요소이므로 채택하지 않았고,
   비대칭 릴리프는 대상 간섭이 존재하지 않아 불필요. S2는 최종 구동 방향에서
   기하학적으로 연속 회전 가능(양방향 모두 무간섭).

2. **슈트 이송(Isaac: 웨지 립 베이에 파편 침전).** rev 1의 수평 바닥 + 4 mm
   립은 전달하지 못했다. 수정: **팬 바닥 연속 하강**(x 83..245.5, z 348 -> 330,
   6.3 deg, S2 재킷 클리어런스 내) + **채널 단계 하강**(x 250.5..350, 2 mm
   net-down 단계, S2 재킷 상면 334.5가 상한 — 벽/가이드 연장으로 하단 봉합).
   수로 전 구간 연속 중력 활주 주장은 하지 않는다(채널 중간의 재킷 상면
   334.5가 하강을 제한); 기하학적 주장은 "팬면 연속 경사 + 모든 단계가 진행
   방향 net-down + 단계 에지 수직 하류면 = 파편 단조 전진"이다. 체크포인트
   재측정: 10/10 PASS (path_check.json).

---

## ADDENDUM 3 (2026-09-23, VP1 Stage 5 활성 오거 — 연결 이송 HOLD)

### 배경과 폐기된 시도

수동 계단/웨지 리브, 패들+스크레이퍼, 얕은 r4/r5 오거는 기하 게이트를
통과했어도 Isaac 시뮬레이션에서 지속 이송하지 못했다. 이 결과는 최종
성공 증거가 아니라 부정 시험 이력으로만 유지한다. 현재 설계는 이전
`x246..261` 수동 적체 구역까지 포함해 x237..354 슈트의 일부를 능동화한다.
S1 팬 전체와 S2 입구의 횡방향 연결은 국부·연결 소재 시험에서 여전히 확인해야 한다.

### 최종 측정 형상

1. **트로프**: x237..354, y213..251의 구조 바닥과 y223.3..240.9
   개방 U-쉘. 측정한 S2 재킷 돔 상면 z334.5를 피하고, x354..360에서
   z330으로 하강한다. BRep 플라이트/U-쉘 최소 간극은 0.032 mm다.
2. **AUG_SHAFT**: 축 +X, `(y232, z347.1)`, 샤프트 r3 x236..370.
   RH 플라이트 root r3 / OD r8, 피치 28.5 mm, 3 mm 축방향 웹,
   네 턴 x238.5..352.5(스윕 외곽 x237.343..354.681).
   전장 모형의 서단 베어링은 x233..239로 S1 팬의 낙하 입구와
   겹친다. x83..237 팬 전체가 능동 플라이트 안에 있다는 뜻이 아니다.
3. **구동**: S2Ecc 12T → PDL_CHAIN 35링크(오프셋 링크) →
   `(x362, z374.5)`의 PDL_SPROCKET/PDL_SHAFT → RH 2-start
   PDL_WORM → 16T AUG_WHEEL. 34링크 명목 길이 323.85 mm는
   중심거리 기준 경로 332.734 mm보다 8.884 mm 짧아 조립 불가였고,
   35링크 333.375 mm는 0.641 mm 남는다. 오프셋 링크 강도와 장력은
   미정격 HOLD다.
   감속비 8:1. 참조 M1 58 rpm에서 15T/40T 기어쌍과 체인 B
   24T/12T를 거친 S2 편심축은 -43.5 rpm이고 오거는 -5.4375 rpm이다.
   RH 플라이트는 음의 회전에서 +x로 이송한다. 이전 -10.875 rpm은
   잭샤프트 전단의 15/40 감속을 빠뜨린 값이므로 폐기한다.
4. **삭제**: 패들, 스크레이퍼, 정적 웨지 리브, 단계형 채널은
   설치하지 않는다. S1 팬의 미구동 구간은 폐기됐다고 주장하지 않는다.

### 검증 경계와 HOLD

- STEP 기하, BRep 간극, 조립 무충돌은 디지털 형상 범위의 증거다.
  과거 국부 17/22 x335 도달은 60초에 M1 130×8회전(1040 rpm)으로
  가속한 비현실적 실행이고, 9/22가 world 유실되었으므로 이송
  합격으로 사용할 수 없다. 16초 연결 실행에서는 오거가 0.75회전해
  피치 기준 최대 21.375 mm만 전진하므로 0/200 B4는 이 시간 구간의
  미도달이다. S1 팬 서측 공급과 S2 입구 횡방향 인계는 별도 결함이다.
- 웜/휠, 축, 베어링, 모터는 **REFERENCE/UNRATED**다. 토크, 효율,
  열, 마모, 수명, 파편 물성 변화와 실제 처리량은 물리 시험 전 미검증이다.
- 본 결정은 구매·제작·통전 승인이 아니다. 해당 단계는 release HOLD를
  유지한다.

## ADDENDUM 4 (2026-09-23, VP1 횡방향 이송과 S2 출력 지지판)

- x≈335의 오거 출구는 S2 입구 y255..295에 직접 들어가지 않는다.
  따라서 S2Ecc→PDL_SHAFT의 기존 동력을 같은 축의 12T 기어로 꺼내어
  중간 12T 아이들러→직교 이송축 12T 두 번의 외부 물림으로 +Y 축의
  우선회 스크루(CROSS_FEED_SHAFT)에 1:1 같은 부호로 전달한다.
  S2Ecc와 이송축은 M1 양의 회전에서 음의 각속도이므로 우선회로
  +Y 이송을 설계한다. 기존 좌선회는 -Y 방향으로 파편을 내보낸
  국부 실행 결과에 따라 폐기했다. 축은 (x357,z328), 루트 r3/외경
  r10, 9 mm 피치, 플라이트 y226..249다. CROSS_FEED_SHELL은 S2
  남쪽 캡을 절삭하지 않고 내경 측 바닥 브리지를 y250.3..258까지
  연장한다. 플라이트 끝에서 입구까지의 수동 구간은 실제 파편 인계의
  합격 판정이 아니다.
- 최종 단면에서 출력 브리지 상면 z317.3을 유지하면서 하단을 z311.8로
  두껍게 했다. STEP BRep 간섭은 0건이다. cap bore 진입 판정은
  y255의 +Y 횡단을 1.5/3 mm 구 전체 외접면의 x350..359.7 출력 립,
  내반경 65.6, 바닥 z317.3과 함께 검사한다(부동소수점 허용 0.0001 mm).
  최종 `flow_localize`의 별도 슈트 주입에서 x335 22/22, 캡 보어
  횡단 18/22, 횡단 후 world 유실 6/22다. 원래 z320..345 임의 판정은
  유효한 하부 통로(z≈318.8의 Ø3 구 중심)를 누락했다. 별도 주입
  성공을 S1에서 연결된 이송 성공으로 확장하지 않는다.
- 기존 S2 후면 출력판은 해당 축/아이들러/베어링 지지대와 BRep에서
  겹쳤다. `build_cad.py`의 rear_feed_mount_clearance는 각 접촉 솔리드의
  국부 footprint만 0.4 mm 마진으로 판면에 파고, 단일 금속 판과
  95% 이상 체적 보존을 요구한다. SUPPORT_TIE_2는 기존 (-75,75)에서
  (-80,80) 국부 XZ로 이동하고 양 지지판에 연결된 연속 금속 타이다.
  이 교정은 CAD 상의 비간섭이지 실제 강도/정격 인증이 아니다.
- PDL_CHAIN의 35링크 오프셋은 정격·장력 확정 전 HOLD다.
- PDL_SPROCKET의 기존 Ø12 보어가 Ø10 샤프트에 헐겁게 끼워져 토크
  경로가 열려 있었다. 샤프트에 y376..392 Ø12 어깨와 1.8 mm 키를
  일체 형성하고 스프로킷 허브에 맞물리는 키 홈을 절삭했다. CAD의
  0.1 mm 키 측면 유격은 물리 키 강도·공차 정격을 증명하지 않는다.
- PDL_WORM/PDL_SHAFT와 AUG_WHEEL/AUG_SHAFT도 기존 공칭 동축 보어만으로
  토크를 전달한다고 볼 수 없어 1.8 mm 키·대응 홈을 각 y220..240,
  x358..362에 추가했다. 해당 축의 회전 접촉과 키 재료·면압은 별도 정격 HOLD.
- S2 편심 입력축에는 y374..386의 구동 12T와 맞물리는 일체 키를
  더했다. 잭샤프트의 제2 24T 드라이버에는 `KEY-6-16` 두 번째
  인스턴스를 y373..387.8(기존 16 mm 재단, 베어링에서 0.2 mm 이격)에
  설치하고 y372.9..387.9 독립 키시트를 설계했다. 샤프트는 단일
  솔리드로 남고 키시트 절삭량과 BRep 비간섭을 통합 결과에 기록한다.
  BOM은 동일 키 수량 2개와 재단·재견적 HOLD를 반영한다.
- 입력축의 삭제된 24T 보어6 스프로킷에만 쓰던 `KEY-4-16_001`도
  제거했다. 활성 BOM은 삭제된 하부 기어/스프로킷/고아 키를 제외하고
  잭샤프트 `KEY-6-16`의 신규 인스턴스를 기존 부품 수량에 합산한다.
- 이산 파편의 S1 공급, x방향 오거 이송, +Y 인계, 스크린 구멍 통과를
  각각 별도 관측하고 최종 제품 소재 흐름은 연결 시험으로만 판정한다.

## ADDENDUM 5 (2026-09-24, 현 VP1 연결 경로 재검증 — 기능 HOLD)

앞선 부록의 `최종` 국부 수치와 형상은 해당 revision의 역사적 증거이며
현 STEP `1d45ad9a…`/USD `b62544c0…`로 승계하지 않는다. 현재 중앙
벨트는 x273 접선까지, 주 오거는 x237..354, 횡이송 플라이트는
y260.502까지 뻗는다. 오거 선반 x273..340의 상면 z337.7,
x340..347 경사 인수면과 x347..354의 바닥 개구, Ø13 내측 버퍼
목은 현 CAD에 있다. BRep 정적 간섭 0건/오거–셸 간극 1.085 mm,
벨트–오거 간격 0.763 mm, 횡이송 축–셸 간격 0.433 mm는
입자 포집·공차·하중·실물 안전의 증명이 아니다.

같은 해시의 독립 Isaac 국부 주입은 S1 배출 22/22에서 주 오거
광의 픽업 3/22이나 벨트 끝을 지난 x285 전진 **0/22**,
슈트 별도 주입의 x335 통과 4/22이나 S2 입구 +Y 인수 **0/22**다.
S2 별도 주입의 동일 Ø4 보어 3/22, 버퍼 상부 19/22,
목 11/22 중 **동일 ID 보어→상부→목은 1/22**뿐이다.
연결 5주기/24,000스텝/200개 실행은 S1 배출 107, 광의 오거 픽업
21, S2 입구·실제 보어·버퍼 상부·목 **각각 0**이다.
`c2.2/results/full_machine/run_20260924_233634/results.json`의
`product_flow_verified=false`/`LOCALIZED_BLOCKED`를 기능 판정으로
유지한다. 일부 입자의 월드 유실도 미해결이다.

따라서 단일 M1 능동 경로는 채택된 *디지털 비교 기준*일 뿐 제품
성공 설계가 아니다. S1 측방 수렴과 오거의 실접촉 전진, 횡이송의
입구 지지·인수, 스크린에서 버퍼 목까지의 같은 입자 포집을
재설계하고 동일 STEP/USD의 연결 시험으로 다시 검증해야 한다.
미정격 구동계와 금속 목 접합·라이너, 열/구조 하중, 물리 안전
게이트와 구매·제작·운전 **HOLD**는 그대로다.

## ADDENDUM 6 (2026-09-25, 동일 입력 재배치 실물 형상 비교 — 채택 보류)

ADDENDUM 5의 수치는 그때의 해시가 붙은 역사적 결과다. 현재 기준안
STEP `875551dd…`/USD `a4611f7d…`의 5주기·24,000스텝·200입자
연결 시험은 S1 배출 108/오거 광의 픽업 42이나 S2 입구·실제 Ø4
보어·버퍼 상부·하부 목 모두 0이다. 별도 S1 주입 x285 전진은 1/22,
슈트 주입 S2 입구 0/22, 별도 S2 주입 동일 보어→목 3/22다.
`c2.2/results/full_machine/run_20260925_064856/results.json` 및 같은
해시의 `flow_localize/results.json`을 현 기준으로 삼는다.

**대안의 실제 형상:** `c2.1/cad/candidates/relocated_gravity.py`가
S2 축을 (308.075,299,215) mm로 내리고 버퍼/압출 카트리지를
−65 mm, M1 덱을 +95.606 mm 이동시킨다. S1 벨트/스위프와 단일
M1·15T/40T 잭·체인 A/B는 보존하고 중앙 벨트/오거/횡이송 대신
전폭 금속 경사 리시버, S2 두 발 레일/네 지지대, M1 네 포스트,
압출 스러스트 발/배럴 받침을 둔다. 74/56링크 체인 명목 피치는
맞지만 장력·정격/샤프트 반력은 HOLD다. STEP `607015bb…`는
246 객체/256 유효 솔리드, 630×414×510 mm 본체, 예상 밖 정확
BRep 교차 0건이다. 외부 출력 포락은 846.505×414×510 mm다.
같은 STEP에서 256 메시·USD `10d53fca…`를 별도 경로로 만들었고
단일 입력 구동 모델의 접속점을 실제 이동 축에 맞췄다.

**기능 판정:** 같은 22개씩의 국부 주입에서 S1 배출 후 리시버
2/22·S2 입구 0/22, 리시버 별도 주입은 S2 입구 2/22,
S2 별도 주입의 동일 보어→목 3/22다. 같은 STEP/USD의 연결
`c2.2/results/full_machine/candidates/relocated_gravity/run_20260925_204332/results.json`
은 S1 배출 116→리시버 5→S2 입구 2→실제 보어 1→버퍼 상부/목 0.
월드 이탈 59/200, S1B 종단 종속 구동 오차 0.5482 rad(허용 0.35)
로 `tracking_pass=false`, 최종 `FAIL`. 해당 국부 결과 참조가
동일 STEP/USD 해시임을 확인했다. 리시버만 넓힌 뒤에도 연결
제품 이송은 되지 않는다.

**선택:** 대안은 단순화된 설계 비교안으로 유지하고 활성 제품을
덮어쓰지 않는다. 동일 물성 대용 모델은 기준안 59.506 kg,
대안 56.147 kg(−3.359 kg 추정)이나 구조/실측 질량이 아니다.
활성 BOM은 기준안 196행 중 미견적 185행, 모터 알려진 착지가격
하한 ₩110,200>₩100,000 소프트 총예산이다. 대안의 신규
용접·지지·체인 재단과 삭제품은 견적/수량 개정 전이므로 가격
절감이라고 주장하지 않는다. 두 안 모두 500 W 경성 운전 상한,
물리 lockout·안전 인터록/퓨즈/정격 HOLD를 유지한다.
다음 설계 선택은 S1 전폭 포집·S2 실제 수신, 실제 보어→버퍼
동일 입자 및 단일 입력 추적을 같은 버전에서 확인한 후 결정한다.

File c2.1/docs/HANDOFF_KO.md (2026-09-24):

# C2.1 VP1 통합 제품 핸드오프

## 현재 결론

C2.1은 S1/S2 공용 M1의 1-DOF 전동계, S1→S2 능동 이송, 압출·냉각,
1.75 mm 풀러와 스풀 와인더, 가드·전장·제어를 하나의 VP1 조립으로
통합한다. 현재 기계 판독 결과는 `results/`, 전체 소재 경로 결과는
`../c2.2/results/full_machine/`, 최종 요약은 루트 `STATUS.md`가 기준이다.

디지털 조립·운동 결과는 소재 연속 이송 성공이나 물리 제작 승인이 아니다.
현재 STEP `e6793f06…`/동일 STEP 원본 USD `41ef9593…`의 19,200-step,
8-cycle 연결 실행에서 S2 스크린 bounding-box 근접은 5/200이며
제품 소재 경로는 **HOLD**다. 이는 스크린 구멍 통과도 아니다.
구매·가공·통전, 물리 운전, main 병합은 명시적 승인 전 **HOLD**다.

## 구현된 제품 경로

- **전동계**: DRV-JACK은 절단 없는 단일 샤프트다. 체인 B는 잭샤프트에서
  S2로 이어지고, S1 헬리컬 기어 물림은 한 쌍만 유지한다.
- **S2**: q=8, e=7 mm. 참조 M1 58 rpm에서 단일 기어쌍 15/40과
  체인 B 24/12를 거친 편심축은 -43.5 rpm, 캐리어는 +5.4375 rpm이다.
  이는 미선정 모터의 참조 회전수에 따른 이상적 속도이며 실물 정격이
  아니다. 별도 S2 모터가 없고 독립 자유도는 하나다.
- **능동 슈트**: 과거 수동 계단, 패들/스크레이퍼와 얕은 오거는
  실패 이력이다. 현재 4회전 오거와 우선회 +Y 횡이송 스크루/쉘은
  BRep 비간섭이다. S1 팬 가이드를 y223..241의 주 오거 벽까지
  수렴시켜 국부 S1 픽업은 5/22에서 12/22로 증가했으나 아직
  비구동 정체·유실이 남았다. USDA 충돌 근사값은
  `UsdPhysics.MeshCollisionAPI`로 명시했다. 이 콜라이더 조건에서
  별도 슈트 주입의 x335 통과는 22/22, cap bore의 y255 +Y
  횡단은 12/22(횡단 이후 유실 5/22)다. 연결 시험의 스크린
  bounding-box 근접은 5/200뿐이다. 최종 판정은 `path_check.json`,
  `flow_localize/results.json`, `run_vp1_final18/results.json`의
  동일 STEP/USD 해시와 함께 읽는다.
- **풀러/와인더**: 1.75 mm 필라멘트용 스프링 니프, 양단 베어링,
  모터-드럼 토크 결합과 트래버스를 실제 조립 형상으로 포함한다.
- **전장**: PSU 24V 33A, 명판 800W. 500W는 경성 운전 예산,
  792W는 별도 PSU 전류 정격 유도 하드웨어 최대값이며 운전 허용치가 아니다.
  단계 제어 정상 피크는 416W(모터/팬은 미정격 모델 추정)다.
- **펌웨어**: host self-test 20건의 전력 할당 로직은 우선순위에 따라
  500W를 넘길 다음 수요를 거부하며 밴드 히터는 한 번에 하나만 허용한다.
  target cross-compile, flash, 실제 통전은 실행하지 않았다.

## 설계 원본과 재생성

- `src/chute.py`, `src/drive_teeth.py`, `src/drive_kinematics.py`,
  `src/winder.py`, `src/electrical_bay.py`: 파라메트릭 원본.
- `src/build_machine_integration.py`: `cad/PPR_VP1.step` 생성과 BRep 검사.
- `src/build_machine_freecad.py`: 편집 가능한 FreeCAD 조립 생성.
- `src/build_system_bom.py`, `src/build_machine_wiring.py`,
  `src/build_firmware.py`: BOM, 배선, host 펌웨어 증거.
- `src/build_release_manifest.py`, `src/verify_artifacts.py`: 최종 해시 고정과
  패키지 검증. 결과 파일을 모두 만든 뒤 manifest를 마지막에 생성한다.

## 남은 HOLD

- M1/M2, 웜/휠, 축, 베어링, coupling의 토크·효율·피로·L10 정격.
- 실제 PLA/PET/TPU 처리량, 입도, jam, 파괴 에너지와 장시간 내구.
- 히터·모터·드라이버의 열평형, 케이블/fuse/contactor/terminal MPN 정격.
- 가드 판 두께, 체결, 파편 containment, interlock의 물리 검증.
- 제조 공차, 윤활, seal, axial retention, 유지보수 절차.
- 실물 E-stop, lid/service interlock, thermal fuse와 branch fuse 시험.

## 재현 순서

저장소 루트에서 관련 생성기를 실행한 뒤 테스트·검증을 수행하고,
`build_release_manifest.py`를 마지막에 실행한다. 구체적인 실행 환경,
통과 건수와 SHA-256은 `STATUS.md` 및 PR 실행 기록을 따른다.

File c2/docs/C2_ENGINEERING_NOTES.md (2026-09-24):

# PPR C2.0 - 첫 번째 실제 설계 반복

기준일: 2026-09-21. C1 기준 SHA: `0aa312c5be0ce566bc06f63fa4fdd5c9e7f3f47e`.
이 문서와 `c2/design/requirements.json`이 진행 중인 C2의 기준이다. 기존 루트 CAD/BOM은 C1 참고본이며, C2 전체 제작도가 아니다.

## 이번에 고정한 것과 고정하지 않은 것
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

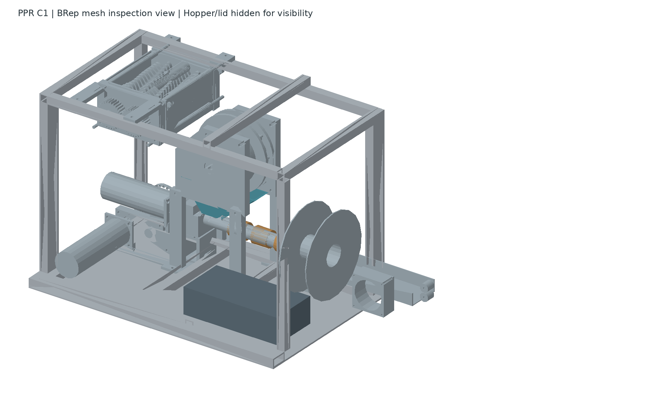
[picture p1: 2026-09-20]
docs/CAD_inspection.png

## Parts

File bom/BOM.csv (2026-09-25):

part_id | description | quantity | material | status | source | notes
FR-2020-360 | 2020 profile cut 360 | 3 | Al extrusion - existing | OWNED_SLOT_PATTERN_TO_MEASURE | PPR_project_handover_2026-09-20.zip / 08_BOM_COMPONENTS.md | Nominal section only. Confirm slot series before buying brackets; 3 mm saw kerf.
FR-2020-400 | 2020 profile cut 400 | 2 | Al extrusion - existing | OWNED_SLOT_PATTERN_TO_MEASURE | PPR_project_handover_2026-09-20.zip / 08_BOM_COMPONENTS.md | Nominal section only. Confirm slot series before buying brackets; 3 mm saw kerf.
FR-2020-590 | 2020 profile cut 590 | 2 | Al extrusion - existing | OWNED_SLOT_PATTERN_TO_MEASURE | PPR_project_handover_2026-09-20.zip / 08_BOM_COMPONENTS.md | Nominal section only. Confirm slot series before buying brackets; 3 mm saw kerf.
FR-2040-320 | 2040 profile cut 320 | 2 | Al extrusion - existing | OWNED_SLOT_PATTERN_TO_MEASURE | PPR_project_handover_2026-09-20.zip / 08_BOM_COMPONENTS.md | Nominal section only. Confirm slot series before buying brackets; 3 mm saw kerf.
FR-2040-400 | 2040 profile cut 400 | 2 | Al extrusion - existing | OWNED_SLOT_PATTERN_TO_MEASURE | PPR_project_handover_2026-09-20.zip / 08_BOM_COMPONENTS.md | Nominal section only. Confirm slot series before buying brackets; 3 mm saw kerf.
FR-2040-630 | 2040 profile cut 630 | 2 | Al extrusion - existing | OWNED_SLOT_PATTERN_TO_MEASURE | PPR_project_handover_2026-09-20.zip / 08_BOM_COMPONENTS.md | Nominal section only. Confirm slot series before buying brackets; 3 mm saw kerf.
FR-BASE | Bottom tray 630x400x3 | 1 | Al 5052 | SHEET_DFM_HOLD | PPR-C1 original dimensional design; not an empirical qualification | Mains and hot zones require separate partitions; shown base is not sealed containment.
EL-PSU | Owned 24V 800W PSU | 1 | Purchased | OWNED_MOUNTING_PATTERN_UNMEASURED | PPR_project_handover_2026-09-20.zip / 08_BOM_COMPONENTS.md | No guessed mounting holes. 120x240x65 user measurement; model contains true body only.
DRV-M1 | M1 TT GMP60 motor reference | 1 | Purchased | DATASHEET_INTERFACE_REFERENCE | https://www.ttmotor.com/uploads/GMP60-609760127.pdf | 4xM5 PCD45, pilot32, shaft12 D10.9; encoder and wire exit not dimensioned in this option.
DRV-M2 | M2 TT GMP60 motor reference | 1 | Purchased | DATASHEET_INTERFACE_REFERENCE | https://www.ttmotor.com/uploads/GMP60-609760127.pdf | 4xM5 PCD45, pilot32, shaft12 D10.9; encoder and wire exit not dimensioned in this option.
DRV-M1-PL | TT60 common motor face plate | 2 | S355 steel | CUSTOM_DFM_HOLD | PPR-C1 original dimensional design; not an empirical qualification | Motor axis datum(35,32.5); 4x5.5 THRU onPCD45. Confirm motor engagement depth.
DRV-CPL12 | Split clamp coupling 12-12 | 1 | Steel | CLAMP_TORQUE_HOLD | PPR-C1 original dimensional design; not an empirical qualification | 2xM5 clamp bolts; friction capacity and motor flat-specific jaw require proof. Not an approved torque limiter.
DRV-IN-SHAFT | Common input shaft 12x157 | 1 | C45 | CUSTOM_DFM_HOLD | PPR-C1 original dimensional design; not an empirical qualification | Bearing journals 12 k6; keyed regions 12 h6. 4 mm key width; retaining collar details in RFQ.
DRV-JACK | Output jackshaft 20x168 | 1 | C45 | CUSTOM_DFM_HOLD | PPR-C1 original dimensional design; not an empirical qualification | 20 k6 bearing seats; 6 mm keyway outside bearing seats. Shoulder/retention specification needs final tolerance audit.
BR-6205 | 6205 bearing boundary | 4 | Bearing steel | DATASHEET_BOUNDARY | https://www.nsk.com/engineering/6205-apn.html | Seal, clearance class and exact suffix must be selected. Bearing envelope is not solid steel in mass estimates.
BR-6001 | 6001 bearing boundary | 4 | Bearing steel | DATASHEET_BOUNDARY | https://www.nsk.com/engineering/6001-apn.html | Seal, clearance class and exact suffix must be selected. Bearing envelope is not solid steel in mass estimates.
BR-6204 | 6204 bearing boundary | 2 | Bearing steel | DATASHEET_BOUNDARY | https://www.nsk.com/engineering/6204-apn.html | Seal, clearance class and exact suffix must be selected. Bearing envelope is not solid steel in mass estimates.
BR-51102 | 51102 bearing boundary | 1 | Bearing steel | DATASHEET_BOUNDARY | https://www.nsk.com/engineering/51102-apn.html | Seal, clearance class and exact suffix must be selected. Bearing envelope is not solid steel in mass estimates.
BR-6202 | 6202 bearing boundary | 1 | Bearing steel | STANDARD_SIZE_VERIFY_MPN | Supplier drawing / capacity confirmation required before procurement | Seal, clearance class and exact suffix must be selected. Bearing envelope is not solid steel in mass estimates.
BR-6007 | 6007 bearing boundary | 2 | Bearing steel | STANDARD_SIZE_VERIFY_MPN | Supplier drawing / capacity confirmation required before procurement | Seal, clearance class and exact suffix must be selected. Bearing envelope is not solid steel in mass estimates.
BR-625 | 625 bearing boundary | 18 | Bearing steel | STANDARD_SIZE_VERIFY_MPN | Supplier drawing / capacity confirmation required before procurement | Seal, clearance class and exact suffix must be selected. Bearing envelope is not solid steel in mass estimates.
DRV-BFRONT | Common front bearing plate | 1 | S355 steel | CUSTOM_DFM_HOLD | PPR-C1 original dimensional design; not an empirical qualification | Two independent bores at56.9402 centres,28 H7 and47 H7. Combined plate avoids overlapping separate housings. Top92.5Z clears M2 can; upper-right corner relief clears coaxial bridge.
DRV-B12 | Input rear bearing plate | 1 | S355 steel | CUSTOM_DFM_HOLD | PPR-C1 original dimensional design; not an empirical qualification | 28 H7; 34 mm local width clears adjacent output sprocket. Attachment/rib stiffness DFM hold.
DRV-B20 | Output rear bearing plate | 1 | S355 steel | CUSTOM_DFM_HOLD | PPR-C1 original dimensional design; not an empirical qualification | 47 H7; metal support with bearing retainers required.
DRV-SH15R | KHK SH2-15RH reference | 1 | S45C hardened | COTS_REFERENCE_SECONDARY_BORE_HOLD | https://khkgears.net/pdf/sh.pdf | Purchased hardened teeth. 25 face + 10 hub. Do not machine teeth from this OD model. 40T bore modified 18 to20. Opposite-hand mating specified; lower-half key is mirrored before axial flip.
DRV-SH15L | KHK SH2-15LH reference | 1 | S45C hardened | COTS_REFERENCE_SECONDARY_BORE_HOLD | https://khkgears.net/pdf/sh.pdf | Purchased hardened teeth. 25 face + 10 hub. Do not machine teeth from this OD model. 40T bore modified 18 to20. Opposite-hand mating specified; lower-half key is mirrored before axial flip.
DRV-SH40R | KHK SH2-40RH reference | 1 | S45C hardened | COTS_REFERENCE_SECONDARY_BORE_HOLD | https://khkgears.net/pdf/sh.pdf | Purchased hardened teeth. 25 face + 10 hub. Do not machine teeth from this OD model. 40T bore modified 18 to20. Opposite-hand mating specified; lower-half key is mirrored before axial flip.
DRV-SH40L | KHK SH2-40LH reference | 1 | S45C hardened | COTS_REFERENCE_SECONDARY_BORE_HOLD | https://khkgears.net/pdf/sh.pdf | Purchased hardened teeth. 25 face + 10 hub. Do not machine teeth from this OD model. 40T bore modified 18 to20. Opposite-hand mating specified; lower-half key is mirrored before axial flip.
DRV-SP24-B20 | ANSI35 24T sprocket bore20 | 1 | Steel | CHAIN_TOOTH_PROFILE_AND_LOAD_HOLD | Supplier drawing / capacity confirmation required before procurement | 9.525 pitch. Roller pocket reference only; exact manufacturer tooth form, width and working load must replace this model.
DRV-SP24-B12 | ANSI35 24T sprocket bore12 | 1 | Steel | CHAIN_TOOTH_PROFILE_AND_LOAD_HOLD | Supplier drawing / capacity confirmation required before procurement | 9.525 pitch. Roller pocket reference only; exact manufacturer tooth form, width and working load must replace this model.
DRV-SP12-B12 | ANSI35 12T sprocket bore12 | 1 | Steel | CHAIN_TOOTH_PROFILE_AND_LOAD_HOLD | Supplier drawing / capacity confirmation required before procurement | 9.525 pitch. Roller pocket reference only; exact manufacturer tooth form, width and working load must replace this model.
DRV-SP24-B25 | ANSI35 24T sprocket bore25 | 1 | Steel | CHAIN_TOOTH_PROFILE_AND_LOAD_HOLD | Supplier drawing / capacity confirmation required before procurement | 9.525 pitch. Roller pocket reference only; exact manufacturer tooth form, width and working load must replace this model.
S1-SPACER-A | S1 spacer A | 12 | Ground C45 | CUSTOM_DFM_HOLD | PPR-C1 original dimensional design; not an empirical qualification | 6.40 +/-0.02 thickness; stack sorted and shimmed. No bearings on these spacers.
S1-CUT-A-P00 | S1 cutter A tooth phase 0 / common key datum | 1 | Tool steel, heat treatment RFQ | CUSTOM_DFM_HOLD | PPR-C1 original dimensional design; not an empirical qualification | Final thickness 6.00 +/-0.02; bore25 H7; key8 Js9. Cut blank then heat-treat/grind, edge hardening not a laser-as-cut assumption. Tooth phase 0.000000 deg; KEY REMAINS ZERO. Mark part phase before grinding.
S1-CUT-A-P01 | S1 cutter A tooth phase 1 / common key datum | 1 | Tool steel, heat treatment RFQ | CUSTOM_DFM_HOLD | PPR-C1 original dimensional design; not an empirical qualification | Final thickness 6.00 +/-0.02; bore25 H7; key8 Js9. Cut blank then heat-treat/grind, edge hardening not a laser-as-cut assumption. Tooth phase 3.956044 deg; KEY REMAINS ZERO. Mark part phase before grinding.
S1-CUT-A-P02 | S1 cutter A tooth phase 2 / common key datum | 1 | Tool steel, heat treatment RFQ | CUSTOM_DFM_HOLD | PPR-C1 original dimensional design; not an empirical qualification | Final thickness 6.00 +/-0.02; bore25 H7; key8 Js9. Cut blank then heat-treat/grind, edge hardening not a laser-as-cut assumption. Tooth phase 7.912088 deg; KEY REMAINS ZERO. Mark part phase before grinding.
S1-CUT-A-P03 | S1 cutter A tooth phase 3 / common key datum | 1 | Tool steel, heat treatment RFQ | CUSTOM_DFM_HOLD | PPR-C1 original dimensional design; not an empirical qualification | Final thickness 6.00 +/-0.02; bore25 H7; key8 Js9. Cut blank then heat-treat/grind, edge hardening not a laser-as-cut assumption. Tooth phase 11.868132 deg; KEY REMAINS ZERO. Mark part phase before grinding.
S1-CUT-A-P04 | S1 cutter A tooth phase 4 / common key datum | 1 | Tool steel, heat treatment RFQ | CUSTOM_DFM_HOLD | PPR-C1 original dimensional design; not an empirical qualification | Final thickness 6.00 +/-0.02; bore25 H7; key8 Js9. Cut blank then heat-treat/grind, edge hardening not a laser-as-cut assumption. Tooth phase 15.824176 deg; KEY REMAINS ZERO. Mark part phase before grinding.
S1-CUT-A-P05 | S1 cutter A tooth phase 5 / common key datum | 1 | Tool steel, heat treatment RFQ | CUSTOM_DFM_HOLD | PPR-C1 original dimensional design; not an empirical qualification | Final thickness 6.00 +/-0.02; bore25 H7; key8 Js9. Cut blank then heat-treat/grind, edge hardening not a laser-as-cut assumption. Tooth phase 19.780220 deg; KEY REMAINS ZERO. Mark part phase before grinding.
S1-CUT-A-P06 | S1 cutter A tooth phase 6 / common key datum | 1 | Tool steel, heat treatment RFQ | CUSTOM_DFM_HOLD | PPR-C1 original dimensional design; not an empirical qualification | Final thickness 6.00 +/-0.02; bore25 H7; key8 Js9. Cut blank then heat-treat/grind, edge hardening not a laser-as-cut assumption. Tooth phase 23.736264 deg; KEY REMAINS ZERO. Mark part phase before grinding.
S1-CUT-A-P07 | S1 cutter A tooth phase 7 / common key datum | 1 | Tool steel, heat treatment RFQ | CUSTOM_DFM_HOLD | PPR-C1 original dimensional design; not an empirical qualification | Final thickness 6.00 +/-0.02; bore25 H7; key8 Js9. Cut blank then heat-treat/grind, edge hardening not a laser-as-cut assumption. Tooth phase 27.692308 deg; KEY REMAINS ZERO. Mark part phase before grinding.
S1-CUT-A-P08 | S1 cutter A tooth phase 8 / common key datum | 1 | Tool steel, heat treatment RFQ | CUSTOM_DFM_HOLD | PPR-C1 original dimensional design; not an empirical qualification | Final thickness 6.00 +/-0.02; bore25 H7; key8 Js9. Cut blank then heat-treat/grind, edge hardening not a laser-as-cut assumption. Tooth phase 31.648352 deg; KEY REMAINS ZERO. Mark part phase before grinding.
S1-CUT-A-P09 | S1 cutter A tooth phase 9 / common key datum | 1 | Tool steel, heat treatment RFQ | CUSTOM_DFM_HOLD | PPR-C1 original dimensional design; not an empirical qualification | Final thickness 6.00 +/-0.02; bore25 H7; key8 Js9. Cut blank then heat-treat/grind, edge hardening not a laser-as-cut assumption. Tooth phase 35.604396 deg; KEY REMAINS ZERO. Mark part phase before grinding.
S1-CUT-A-P10 | S1 cutter A tooth phase 10 / common key datum | 1 | Tool steel, heat treatment RFQ | CUSTOM_DFM_HOLD | PPR-C1 original dimensional design; not an empirical qualification | Final thickness 6.00 +/-0.02; bore25 H7; key8 Js9. Cut blank then heat-treat/grind, edge hardening not a laser-as-cut assumption. Tooth phase 39.560440 deg; KEY REMAINS ZERO. Mark part phase before grinding.
S1-CUT-A-P11 | S1 cutter A tooth phase 11 / common key datum | 1 | Tool steel, heat treatment RFQ | CUSTOM_DFM_HOLD | PPR-C1 original dimensional design; not an empirical qualification | Final thickness 6.00 +/-0.02; bore25 H7; key8 Js9. Cut blank then heat-treat/grind, edge hardening not a laser-as-cut assumption. Tooth phase 43.516484 deg; KEY REMAINS ZERO. Mark part phase before grinding.
S1-CUT-A-P12 | S1 cutter A tooth phase 12 / common key datum | 1 | Tool steel, heat treatment RFQ | CUSTOM_DFM_HOLD | PPR-C1 original dimensional design; not an empirical qualification | Final thickness 6.00 +/-0.02; bore25 H7; key8 Js9. Cut blank then heat-treat/grind, edge hardening not a laser-as-cut assumption. Tooth phase 47.472527 deg; KEY REMAINS ZERO. Mark part phase before grinding.
S1-SHAFT-A | S1 shaft A 25x282 | 1 | C45 or SCM440 certified | CUSTOM_DFM_HOLD | PPR-C1 original dimensional design; not an empirical qualification | 25 k6 at y40..55 and231..246; cutter/key lands25 h6. Keyways must not cross journals. Retention collars required; step/fillet audit pending.
S1-SPACER-B | S1 spacer B | 12 | Ground C45 | CUSTOM_DFM_HOLD | PPR-C1 original dimensional design; not an empirical qualification | 6.40 +/-0.02 thickness; stack sorted and shimmed. No bearings on these spacers.
S1-CUT-B-P00 | S1 cutter B tooth phase 0 / common key datum | 1 | Tool steel, heat treatment RFQ | CUSTOM_DFM_HOLD | PPR-C1 original dimensional design; not an empirical qualification | Final thickness 6.00 +/-0.02; bore25 H7; key8 Js9. Cut blank then heat-treat/grind, edge hardening not a laser-as-cut assumption. Tooth phase 0.000000 deg; KEY REMAINS ZERO. Mark part phase before grinding.
S1-CUT-B-P01 | S1 cutter B tooth phase 1 / common key datum | 1 | Tool steel, heat treatment RFQ | CUSTOM_DFM_HOLD | PPR-C1 original dimensional design; not an empirical qualification | Final thickness 6.00 +/-0.02; bore25 H7; key8 Js9. Cut blank then heat-treat/grind, edge hardening not a laser-as-cut assumption. Tooth phase 3.956044 deg; KEY REMAINS ZERO. Mark part phase before grinding.
S1-CUT-B-P02 | S1 cutter B tooth phase 2 / common key datum | 1 | Tool steel, heat treatment RFQ | CUSTOM_DFM_HOLD | PPR-C1 original dimensional design; not an empirical qualification | Final thickness 6.00 +/-0.02; bore25 H7; key8 Js9. Cut blank then heat-treat/grind, edge hardening not a laser-as-cut assumption. Tooth phase 7.912088 deg; KEY REMAINS ZERO. Mark part phase before grinding.
S1-CUT-B-P03 | S1 cutter B tooth phase 3 / common key datum | 1 | Tool steel, heat treatment RFQ | CUSTOM_DFM_HOLD | PPR-C1 original dimensional design; not an empirical qualification | Final thickness 6.00 +/-0.02; bore25 H7; key8 Js9. Cut blank then heat-treat/grind, edge hardening not a laser-as-cut assumption. Tooth phase 11.868132 deg; KEY REMAINS ZERO. Mark part phase before grinding.
S1-CUT-B-P04 | S1 cutter B tooth phase 4 / common key datum | 1 | Tool steel, heat treatment RFQ | CUSTOM_DFM_HOLD | PPR-C1 original dimensional design; not an empirical qualification | Final thickness 6.00 +/-0.02; bore25 H7; key8 Js9. Cut blank then heat-treat/grind, edge hardening not a laser-as-cut assumption. Tooth phase 15.824176 deg; KEY REMAINS ZERO. Mark part phase before grinding.
S1-CUT-B-P05 | S1 cutter B tooth phase 5 / common key datum | 1 | Tool steel, heat treatment RFQ | CUSTOM_DFM_HOLD | PPR-C1 original dimensional design; not an empirical qualification | Final thickness 6.00 +/-0.02; bore25 H7; key8 Js9. Cut blank then heat-treat/grind, edge hardening not a laser-as-cut assumption. Tooth phase 19.780220 deg; KEY REMAINS ZERO. Mark part phase before grinding.
S1-CUT-B-P06 | S1 cutter B tooth phase 6 / common key datum | 1 | Tool steel, heat treatment RFQ | CUSTOM_DFM_HOLD | PPR-C1 original dimensional design; not an empirical qualification | Final thickness 6.00 +/-0.02; bore25 H7; key8 Js9. Cut blank then heat-treat/grind, edge hardening not a laser-as-cut assumption. Tooth phase 23.736264 deg; KEY REMAINS ZERO. Mark part phase before grinding.
S1-CUT-B-P07 | S1 cutter B tooth phase 7 / common key datum | 1 | Tool steel, heat treatment RFQ | CUSTOM_DFM_HOLD | PPR-C1 original dimensional design; not an empirical qualification | Final thickness 6.00 +/-0.02; bore25 H7; key8 Js9. Cut blank then heat-treat/grind, edge hardening not a laser-as-cut assumption. Tooth phase 27.692308 deg; KEY REMAINS ZERO. Mark part phase before grinding.
S1-CUT-B-P08 | S1 cutter B tooth phase 8 / common key datum | 1 | Tool steel, heat treatment RFQ | CUSTOM_DFM_HOLD | PPR-C1 original dimensional design; not an empirical qualification | Final thickness 6.00 +/-0.02; bore25 H7; key8 Js9. Cut blank then heat-treat/grind, edge hardening not a laser-as-cut assumption. Tooth phase 31.648352 deg; KEY REMAINS ZERO. Mark part phase before grinding.
S1-CUT-B-P09 | S1 cutter B tooth phase 9 / common key datum | 1 | Tool steel, heat treatment RFQ | CUSTOM_DFM_HOLD | PPR-C1 original dimensional design; not an empirical qualification | Final thickness 6.00 +/-0.02; bore25 H7; key8 Js9. Cut blank then heat-treat/grind, edge hardening not a laser-as-cut assumption. Tooth phase 35.604396 deg; KEY REMAINS ZERO. Mark part phase before grinding.
S1-CUT-B-P10 | S1 cutter B tooth phase 10 / common key datum | 1 | Tool steel, heat treatment RFQ | CUSTOM_DFM_HOLD | PPR-C1 original dimensional design; not an empirical qualification | Final thickness 6.00 +/-0.02; bore25 H7; key8 Js9. Cut blank then heat-treat/grind, edge hardening not a laser-as-cut assumption. Tooth phase 39.560440 deg; KEY REMAINS ZERO. Mark part phase before grinding.
S1-CUT-B-P11 | S1 cutter B tooth phase 11 / common key datum | 1 | Tool steel, heat treatment RFQ | CUSTOM_DFM_HOLD | PPR-C1 original dimensional design; not an empirical qualification | Final thickness 6.00 +/-0.02; bore25 H7; key8 Js9. Cut blank then heat-treat/grind, edge hardening not a laser-as-cut assumption. Tooth phase 43.516484 deg; KEY REMAINS ZERO. Mark part phase before grinding.
S1-CUT-B-P12 | S1 cutter B tooth phase 12 / common key datum | 1 | Tool steel, heat treatment RFQ | CUSTOM_DFM_HOLD | PPR-C1 original dimensional design; not an empirical qualification | Final thickness 6.00 +/-0.02; bore25 H7; key8 Js9. Cut blank then heat-treat/grind, edge hardening not a laser-as-cut assumption. Tooth phase 47.472527 deg; KEY REMAINS ZERO. Mark part phase before grinding.
S1-SHAFT-B | S1 shaft B 25x250 | 1 | C45 or SCM440 certified | CUSTOM_DFM_HOLD | PPR-C1 original dimensional design; not an empirical qualification | 25 k6 at y40..55 and231..246; cutter/key lands25 h6. Keyways must not cross journals. Retention collars required; step/fillet audit pending. Front gear key6deg; cutter key0deg.
S1-SYNC | KHK SS2-30HJ25 reference | 2 | S45C hardened | COTS_TOOTH_REFERENCE | https://khkgears.net/pdf/ss.pdf | Pitch60 OD64; face20 hub10. Involute reference has simplified root. Purchase manufacturer gear, do not cut from this model.
S1-BPL | S1 bearing carrier | 2 | S355 steel | CUSTOM_DFM_HOLD | PPR-C1 original dimensional design; not an empirical qualification | Two 52 H7 seats at60.00 +/-0.02 centres. Line bore assembled metal carriers. Datums A face, B base, C left edge.
S1-WALL | S1 metal end liner | 2 | S355 wear liner | CUSTOM_DFM_HOLD | PPR-C1 original dimensional design; not an empirical qualification | Wear liner shaft opening26; not bearing seat. Ground/shimmed cutter end gap0.60 nominal. FourD12.4 edge-reliefs atX10/150,Z6/86 clear metal tie spacers.
S1-SIDE | S1 side containment strip | 2 | 3mm steel | CUSTOM_DFM_HOLD | PPR-C1 original dimensional design; not an empirical qualification | Two steel side liners. Upper inlet and lower outlet intentionally open inside interlocked enclosure.
S1-BR-CAP | Two-bearing retainer | 2 | S355 steel | CUSTOM_DFM_HOLD | PPR-C1 original dimensional design; not an empirical qualification | 47 mm inner abutment per NSK6205; four M6 through bolts share carrier pattern. No overlapping round caps.
S2-GUIDE | 8-lobe cycloidal guide, 9 fixed pins | 1 | C45 surface treatment RFQ | CUSTOM_DFM_HOLD | PPR-C1 original dimensional design; not an empirical qualification | Rpin72 / e7 / rollerR8; analytic offset allowance0.20. 8x5.5 onPCD70. Profile generated from analytic equations; contact fatigue/backlash NOT qualified.
S2-ROTOR | S2 8-hook rotor110, bearing cartridge | 1 | C45 / wear inserts RFQ | CUSTOM_DFM_HOLD | PPR-C1 original dimensional design; not an empirical qualification | Active40; total70; 2x62 H7 counterbores14 deep; minimum wall and heat treatment DFM needed. Inserts vs monolithic material not yet closed.
S2-ECC | Eccentric sleeve35 / bore12 / e7 | 1 | C45 | CUSTOM_DFM_HOLD | PPR-C1 original dimensional design; not an empirical qualification | Outside35 k6, bore12 H7, eccentricity7.00 +/-0.01; minimum geometric wall4.5. Separate sleeve permits bearing/rotor assembly; torque, key and fatigue validation pending.
S2-SHAFT | S2 drive shaft12x189 | 1 | C45 | CUSTOM_DFM_HOLD | PPR-C1 original dimensional design; not an empirical qualification | Drive is one centred shaft plus removable eccentric sleeve, not an unassembleable integral crank. 12 k6 bearing seats.
S2-SUP | S2 chamfered main shaft support | 2 | C45 | CUSTOM_DFM_HOLD | PPR-C1 original dimensional design; not an empirical qualification | 28 H7 main bearing seat. Upper-left70mm chamfer clears S1 carrier; add metal rail support before load release.
S2-PIN-F | Fixed pin ring F | 1 | C45 | CUSTOM_DFM_HOLD | PPR-C1 original dimensional design; not an empirical qualification | 9x5 H7 holes onPCD144; 40deg pitch. Select precision shoulder pins, not threaded bolt shanks. Plate stays fixed.
S2-PIN-R | Fixed pin ring R | 1 | C45 | CUSTOM_DFM_HOLD | PPR-C1 original dimensional design; not an empirical qualification | 9x5 H7 holes onPCD144; 40deg pitch. Select precision shoulder pins, not threaded bolt shanks. Plate stays fixed.
S2-PIN | Precision roller pin5x31 | 9 | Bearing steel | CUSTOM_DFM_HOLD | PPR-C1 original dimensional design; not an empirical qualification | Supported at both ends by fixed ring plates. Axial retaining hardware not yet released.
S2-CASE-L | S2 steel shell arc L | 1 | 3mm steel | CUSTOM_DFM_HOLD | PPR-C1 original dimensional design; not an empirical qualification | ID125.6 wall3. Two discrete shell arcs leave feed80deg and screen100deg. Flanges/fasteners must be finalised.
S2-CASE-R | S2 steel shell arc R | 1 | 3mm steel | CUSTOM_DFM_HOLD | PPR-C1 original dimensional design; not an empirical qualification | ID125.6 wall3. Two discrete shell arcs leave feed80deg and screen100deg. Flanges/fasteners must be finalised.
S2-SCREEN | Curved screen4mm x78 holes | 1 | 2mm steel | CUSTOM_DFM_HOLD | PPR-C1 original dimensional design; not an empirical qualification | 4 mm round holes, pitch6 axial. Bent radius inner62.8. Hole size is not a guaranteed maximum particle length. Flat DXF generated separately.
FEED-BUF | Steel receiver190x48 top /Ø20 neck | 1 | S355 steel | CUSTOM_DFM_HOLD | PPR-C1 original dimensional design; not an empirical qualification | Original 190x48 mouth at z218, outer envelope z145..218; inset at z210 has inner x247..358,y255.5..294.5, enclosing nominal screen bores. Lower Ø13 clear octagonal throat at x299,y275,z145 with Ø20 outer neck z145..160 and steel saddle; fasteners, weld, sealing, thermal fit and fabrication DFM remain HOLD. No material-flow or physical-release claim.
FEED-BUF-SADDLE | Upper cold-barrel saddle and feed sleeve | 1 | S355 steel | CUSTOM_DFM_HOLD | PPR-C1 original dimensional design; not an empirical qualification | Sleeve joins FEED-BUF lower steel face at z145 by qualified weld; upper half of Ø36/Ø30.2 x34 cold-barrel split clamp, 0.4 mm open seam and four M5 through-holes. Bolt preload, weld, seal and thermal fit remain DFM HOLD.
FEED-BUF-CLAMP | Lower cold-barrel saddle half | 1 | S355 steel | CUSTOM_DFM_HOLD | PPR-C1 original dimensional design; not an empirical qualification | Lower half of FEED-BUF-SADDLE; four M5 holes pair upper ears. Ø30.2 nominal bore on Ø30 barrel has 0.1 mm cold radial clearance, with 0.4 mm seam available for preload; torque and metal-to-barrel seal remain DFM HOLD.
EX-SCREW | 16mm x256mm compression screw | 1 | SCM440 QT/nitriding RFQ | CUSTOM_DFM_HOLD | PPR-C1 original dimensional design; not an empirical qualification | Pitch16, flight2, root10 feed /13 meter, L/D16. CAD flight has square flanks; fillets/tip geometry/finish and nitriding supplier confirmation required.
EX-BARREL | Barrel16.3ID x30OD x256 | 1 | SCM440 nitrided RFQ | CUSTOM_DFM_HOLD | PPR-C1 original dimensional design; not an empirical qualification | Radial cold clearance0.15. Honing, straightness, hot fit, feed hole and die pressure sealing require supplier approval.
EX-REAR | Extruder rear/thrust shaft15 | 1 | SCM440 | CUSTOM_DFM_HOLD | PPR-C1 original dimensional design; not an empirical qualification | x213..274 inassembly; collar258..264. No thrust transmitted to M2 bearings; shaft-screw connection detail is manufacturing HOLD.
EX-CPL | 12-to15 split coupling32 long | 1 | Steel | CLAMP_TORQUE_HOLD | PPR-C1 original dimensional design; not an empirical qualification | D-shaft jaw and clamping proof pending, no axial load transfer intent.
EX-THRUST | Metal thrust carrier39x60x70 | 1 | C45 | CUSTOM_DFM_HOLD | PPR-C1 original dimensional design; not an empirical qualification | 6202 and51102 distinct radial/thrust functions. Split lid, positive stops and end access need assembly DFM; digital solid only. Four M6 underside pilots atX10/26,Y10/50; mating stand positions232/248,255/295.
EX-DIE | Die36OD x20 with2mm exit | 1 | SCM440 or stainless RFQ | CUSTOM_DFM_HOLD | PPR-C1 original dimensional design; not an empirical qualification | 2mm die exit is a drawdown candidate for1.75 filament, not final calibration. Heater bore6x38; pressure attachment not yet detailed.
EX-H100 | 24V100W band heater30ID x40 | 3 | Purchased custom | HEATER_QUOTE_AND_DRAWING_HOLD | Supplier drawing / capacity confirmation required before procurement | 3units100W; power density100/(pi*3cm*4cm)=2.65W/cm2. Lead/clamp bulge not invented.
EX-H60 | 24V60W cartridge6x20 | 1 | Purchased custom | HEATER_QUOTE_AND_DRAWING_HOLD | Supplier drawing / capacity confirmation required before procurement | Rated60W is requirement, not a verified off-the-shelf product.
COOL-TRAY | Air cooling trough275x80 | 1 | Sheet metal | CUSTOM_DFM_HOLD | PPR-C1 original dimensional design; not an empirical qualification | 275mm working length. Filament path125Z; thermal model determines throughput; fans require a measured duct curve.
COOL-FAN | Sanyo9RA0824H1001 | 2 | Purchased | DATASHEET_BODY_HOLE_PATTERN_VERIFY | https://products.sanyodenki.com/en/sanace/dc/dc-fan/9RA0824H1001/ | 80x80x38,24V0.33A7.92W; mounting pattern must use final manufacturer drawing. Tach, no PWM pin.
SPOOL-ENV | 200mm x70 spool reference | 1 | User spool reference | SPOOL_INTERFACE_ONLY | Supplier drawing / capacity confirmation required before procurement | Side-removable, support shaft/bracket/traverse and powered tensioning remain unqualified.
PULL-ROLLER | Puller roller20x22 | 2 | TPU tread / metal hub | CUSTOM_DFM_HOLD | PPR-C1 original dimensional design; not an empirical qualification | 2 rollers,one compliant preload. Drive motor/tach and spring stack not yet manufacturing released.
HOPPER | 35deg batch hopper | 1 | PC shell + steel lower liner | CUSTOM_DFM_HOLD | PPR-C1 original dimensional design; not an empirical qualification | Whole hopper exceeds print limit; must split into <=210mm panels before printing. Closed lid and standstill interlock mandatory; angle is not an access safety measure.
HOP-LID | Interlocked lid180x140 | 1 | PC with metal strike | CUSTOM_DFM_HOLD | PPR-C1 original dimensional design; not an empirical qualification | Hinge/guard lock hardware not chosen. NO open-lid operation.
FR-2020-320 | 2020 profile cut320 | 1 | Al extrusion - existing | OWNED_SLOT_PATTERN_TO_MEASURE | PPR_project_handover_2026-09-20.zip / 08_BOM_COMPONENTS.md | Nominal section only. Confirm slot series before buying brackets; 3 mm saw kerf.
S1-TIE-TUBE | Ground carrier spacer12OD x175 | 4 | C45 | CUSTOM_DFM_HOLD | PPR-C1 original dimensional design; not an empirical qualification | 175.00 +/-0.02; four tubes clamp front/rear carriers into one metal cartridge. Bore6.6; do not substitute printed struts.
S1-STUD | M6 threaded rod270 nominal | 4 | Steel fastener | FASTENER_RATING_VERIFY | PPR-C1 original dimensional design; not an empirical qualification | 4 studs,270mm; thread geometry not modelled. Select proof-load certified rods/nuts.
S1-ROOF-F | Front roof bracket30x95x25 | 2 | 10mm steel welded/folded | CUSTOM_DFM_HOLD | PPR-C1 original dimensional design; not an empirical qualification | Face atY135 against retainer. M6 top hole to existing profile centreY50. Metal roof load path; bend/weld qualification pending.
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

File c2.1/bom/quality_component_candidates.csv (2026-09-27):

category | manufacturer_mpn | vendor | required_quantity | listed_unit_price | currency | listing_scope | source_url | observed_date | comparison_and_evidence_limits | unquoted_costs_and_gates
contact_Hall | Adafruit TMAG5273A1 breakout product 6489 | Adafruit | 2 | 5.95 | USD | One assembled 3D Hall breakout at 1-9 quantity; two listed units total USD 11.90 excluding all other components | https://www.adafruit.com/product/6489 | 2026-09-27 | Two independently mounted axes can measure X and Y lever displacement and ovality; I2C magnetic signal is not a diameter accuracy specification; calibration must include lever geometry magnet position temperature hysteresis and low-force contact deformation of PLA PET and especially TPU | Two magnets; two levers and pivots; compliant contact rollers and springs; mounts harness controller integration calibration labor tax shipping import and landed KRW all unquoted; no achieved ±0.05 or ±0.03 mm claim
optical_line_array | Generic TSL1401CL wide-angle-lens module code TSL1401 | Micro Robotics South Africa | 2 | 675.00 | ZAR | One 128x1 camera module R675.00 excluding local tax (R776.25 including local tax); two modules R1350.00 excluding local tax; Stellenbosch limited stock and Centurion no stock | https://www.robotics.org.za/TSL1401 | 2026-09-27 | Two orthogonal backlit sightlines could avoid TPU contact deformation and show ovality; stated 8.12 mm active length/128 pixels gives about 0.0634 mm sensor-plane pitch (computed), NOT object-space accuracy; wide-angle lens magnification edge detection and transparent PLA PET TPU contrast unverified | Two backlights diffusers optical shields brackets camera acquisition interface controller integration and calibration; shipment to Korea tax customs and landed KRW all unquoted; transparent stock with bubbles/glare must be demonstrated
reference_pin | Insize 4110-1D75 1.75 mm Grade 1 individual steel pin | Cutwel UK | 1 | 14.712001 | GBP | One 1.75 mm pin; price from product:price metadata; VAT inclusion not explicit in extracted product quote | https://www.cutwel.co.uk/1-75mm-individual-pin-gauge-grade-1-4110-series-insize-4110-1d75 | 2026-09-27 | Nominal reference checks both axes at one diameter only; listing says Grade 1 DIN2267 but does not provide an individual traceable calibration certificate or uncertainty; nominal size alone cannot establish sensor scale/hysteresis across ±0.05 mm | Additional 1.70 and 1.80 mm certified references and actual certificates or independent micrometer checks; delivery VAT import landed KRW unquoted
bench_micrometer | Fowler 522400011 0-1 inch outside micrometer | Fowler High Precision | 1 | 52.00 | USD | One sale-price instrument; seller also displays USD 57.00 list; cart calculates shipping and taxes later | https://fowlerprecision.com/products/fowler-0-1-outside-inch-micrometer-3 | 2026-09-27 | Maker states 0.0001 inch graduation and ±0.00015 inch accuracy; bench spot checks over length and orientations independently of online gauge; friction thimble still imposes contact on soft TPU | Traceability certificate; gauge force/repeatability study; shipment to Korea tax import landed KRW and a measured reference set all unquoted; borrowed verified instrument may avoid purchase
clutch_rejected_reference | Traxxas 4615 slipper clutch set complete retailer SKU Z-TRX4615 | Model Maker UK | 1 | 15.95 | GBP | One RC slipper clutch complete at sale price versus GBP 18.95 original; explicitly out of stock | https://model-maker.co.uk/product/radio-control/hardware-radio-control-2/spares/transmission-drivetrain/slipper-clutch-set-complete/ | 2026-09-27 | Not a qualified filament winder clutch; no published torque range shaft fit or continuous-slip thermal rating on this listing; price cannot stand in for priced tension decoupling or safety control | Qualified clutch or dancer-drive torque control specification and supplier RFQ; adapters guarding thermal validation shipping taxes import landed KRW unquoted
power_supply_replacement_only | JMDISPLAY 12V/24V 800W selectable product 65 | JMDISPLAY | 1 | 95000 | KRW | Donor PSU failure contingency only; generic display KRW 95000; 24V 800W selectable; KRW 2500 posted parcel shipping before checkout | https://crpkrjang.cafe24.com/product/smps-12v24v-800w-%EC%82%B0%EC%97%85%EC%9A%A9-%EC%A0%84%EC%9B%90%EA%B3%B5%EA%B8%B0/65/ | 2026-09-27 | User now reports Chiron donor PSU 24V 800W and 240x120x65 mm exterior; label and mount fit unverified. This replacement listing is not a required purchase or the same PSU; exact 24V option price stock exterior sustained output protection and certification unverified | Qualify donor PSU label mounting pattern condition and 500W staged duty first; replacement checkout price delivery region mounting wiring mains isolation thermal protection and landed KRW remain unquoted
emergency_stop_replacement_only | DECA A20B-V4E02R+A2AV-27 PP-B321 2NC | Parts-Parts | 1 | 15000 | KRW | Replacement comparison only; seller displays KRW 15000 and KRW 3000 delivery below KRW 100000 cart value | https://parts-parts.co.kr/product/pp-b321-22%ED%8C%8C%EC%9D%B4-%EB%B9%84%EC%83%81%EC%8A%A4%EC%9C%84%EC%B9%98%EB%B9%84%EC%83%81%EC%A0%95%EC%A7%80%EB%AA%85%ED%8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 | 2026-09-27 | User reports one owned 2NC stop button sized 35x35 mm with dimension target and model unknown; this DECA listing is NOT the owned part or a required purchase. Both still need contact rating positive-opening panel fit wiring and independent hard-cut validation | Safety contactor relay interlocks fuses enclosure lockout and physical qualification remain unquoted even if the button can be reused
power_supply_Ali_replacement_only_unqualified | S-800-24 selectable voltage AliExpress item 33059280218 | AliExpress marketplace | 1 |  | KRW | Donor PSU failure contingency only; 24V 33A title and 110V or 220V input options; KRW 58000 observed for default 110V selection only; 24V+220V variant price and Korea shipping not verified | https://www.aliexpress.com/item/33059280218.html | 2026-09-27 | User owns Chiron donor PSU; this is not current required purchase. Exact 220V variant not priced; 24V*33A=792W versus 800W model name; 240x120x65 envelope certification sustained output and protection unverified | Verify donor first; if unfit obtain replacement exact nameplate >=800W drawing certification shipping tax and returns; mains remains HOLD
motor_M1_Ali_unqualified | AliExpress item 32899600460 57mm brake BLDC 24V 200W 3000rpm | AliExpress marketplace | 1 |  | KRW | Public title identifies brake motor but no trustworthy exact motor+driver variant price shipping or shaft drawing | https://www.aliexpress.com/item/32899600460.html | 2026-09-27 | M1 output torque shaft size rated current brake driver gearing and S1/S2 shared-drive duty unverified; 200W headline does not qualify cutter torque or cost | Driver reduction mount protection shipping and whole-product landed cost unquoted; no purchase or motor selection
reference_PLA_domestic | Taekang PLA pellet selectable 1kg product 738 | 3Dprinterstore Korea | 1 | 11000 | KRW | 1kg option KRW 11000 + posted nationwide parcel KRW 4000 = conditional KRW 15000 before checkout; islands may cost more | https://3dprinterstore.co.kr/product/%ED%83%9C%EA%B0%95-pla-%ED%8E%A0%EB%A6%BF-pellet/738/ | 2026-09-27 | Candidate for same final extruder reference-feed test only; seller says NatureWorks raw but resin grade lot melt-flow moisture and pellet dimensions are not published; not evidence for recycled material quality | Checkout stock grade datasheet drying and moisture measurement calibration delivery plus rejected startup material needed; quote only, no order or physical-test approval
reference_PLA_import | ARTME Ingeo 4043D natural PLA pellets selectable 0.5kg | ARTME 3D | 1 | 5.04 | EUR | 0.5kg EUR 5.04 + published worldwide <=2kg shipping EUR 25 = conditional EUR 30.04 before tax; Korea checkout and packed weight unconfirmed | https://artme-3d.shop/products/pla-pellets | 2026-09-27 | Named 4043D grade helps reproducibility but 0.5kg pack and shipping are not a cheaper KRW landed quote; not directly comparable to domestic 1kg and no dried moisture measurement | Shipping policy https://artme-3d.shop/policies/shipping-policy; verify Korea checkout grade batch datasheet packaging drying tax import and trial quantity before selection; quote only, no order

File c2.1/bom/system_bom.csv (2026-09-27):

scope | part_id | description | quantity | material | status | source | evidence | landed_line_KRW | cost_state | notes
active_S2_C2.1 | S2-CYC-ROTOR | fused CAD envelope for cycloid disc hook rotor and web | 1 | C45/tool insert concept | DFM_AND_STRESS_HOLD | C2.1-CAD | E2 |  | UNKNOWN | Physical bolts fits axial retention heat treatment tolerance and load are unmodeled
active_S2_C2.1 | S2-ECC-BEARING | eccentric rotor bearing envelope | 1 | MPN unselected | BEARING_RATING_HOLD | C2.1-ADR | E0 |  | UNKNOWN | Boundary only; oscillating combined load unknown
active_S2_C2.1 | S2-FASTENERS | rotor/ring/support fasteners axial stops and retainers | 1 | certified steel hardware required | HARDWARE_SCHEDULE_HOLD | C2.1-ADR | E0 |  | UNKNOWN | Not modeled; quantity grade preload fit retention and cost unknown
active_S2_C2.1 | S2-FIXED-PIN | fixed reaction ring pin | 9 | hardened steel candidate | CONTACT_RATING_HOLD | C2.1-CAD | E2 |  | UNKNOWN | Pin/roller contact stress lubrication and retention unknown
active_S2_C2.1 | S2-GUARD | guard section envelope | 1 | metal containment required | SAFETY_DESIGN_HOLD | C2-REQ | E0 |  | UNKNOWN | Envelope is not a complete or certified guard
active_S2_C2.1 | S2-IN-BEARING | input support bearing envelope | 1 | MPN unselected | BEARING_RATING_HOLD | C2.1-ADR | E0 |  | UNKNOWN | Boundary only; speed/load/life/seal unknown
active_S2_C2.1 | S2-IN-SHAFT | input shaft with eccentric crank | 1 | C45 candidate | LOAD_RATING_HOLD | C2.1-CAD | E2 |  | UNKNOWN | Key/spline/fatigue/fit not released
active_S2_C2.1 | S2-OUT-BEARING | output shaft bearing envelope | 1 | MPN unselected | BEARING_RATING_HOLD | C2.1-ADR | E0 |  | UNKNOWN | Boundary only; radial/axial load and life unknown
active_S2_C2.1 | S2-OUT-CARRIER | output pin carrier and shaft | 1 | steel candidate | FATIGUE_AND_FIT_HOLD | C2.1-CAD | E2 |  | UNKNOWN | Fixed-axis output rotates -1/q
active_S2_C2.1 | S2-OUT-ROLLER | offset-accommodation roller envelope | 6 | MPN unselected | COUPLING_RATING_HOLD | C2.1-ADR | E0 |  | UNKNOWN | Window R12.2 gives e7 plus0.2 nominal clearance only; loaded phase/contact sharing HOLD
active_S2_C2.1 | S2-RING-PLATE | fixed reaction plate | 2 | steel candidate | STRESS_AND_DFM_HOLD | C2.1-CAD | E2 |  | UNKNOWN | 6mm is a CAD assumption not an approved plate
active_S2_C2.1 | S2-SCREEN | VP1 gravity-aligned perforated curved screen | 1 | steel candidate | SCREEN_CALIBRATION_HOLD | C2.1-CAD | E2 |  | UNKNOWN | Current C2.1 generated screen has 78 straight Ø3 exit paths into buffer; particle capture flow ligament strength mounting and particle length limit remain unverified
active_S2_C2.1 | S2-SCREEN-PERF | screen cassette attachment and seal hardware | 1 | metal hardware required | ATTACHMENT_HARDWARE_HOLD | C2-REQ | E0 |  | UNKNOWN | Perforated screen geometry exists; removable cassette fasteners seal and cleanout access are not modeled
active_S2_C2.1 | S2-SENSORS | shear screen motor gear ambient sensors and harness | 1 | qualified sensors required | SENSOR_SELECTION_WIRING_RESPONSE_HOLD | C2-REQ | E1 |  | UNKNOWN | Shear sensor bore exists; sensor MPN mounts wiring calibration delay and response validation remain HOLD
active_S2_C2.1 | S2-SHEAR | fixed shear with sensor blind-bore geometry | 1 | tool steel candidate | LOAD_THERMAL_HOLD | C2-CAD | E2 |  | UNKNOWN | Actual C2 generated geometry is integrated; retention edge treatment sensor selection and response remain HOLD
active_S2_C2.1 | S2-SUPPORT-PLATE | chamfered front/rear shaft support plate | 2 | steel candidate | FRAME_INTEGRATION_DIGITAL_PASS_RATING_HOLD | C2.1-CAD | E2 |  | UNKNOWN | C1 S1 clearance and four relocated metal-leg face interfaces pass digital BRep; fastener/preload/stiffness remain HOLD
active_S2_C2.1 | S2-SUPPORT-TIE | axial metal tie rod | 4 | certified steel rod candidate | FRAME_INTEGRATION_DIGITAL_PASS_RATING_HOLD | C2.1-CAD | E2 |  | UNKNOWN | Digital clearance passes; thread grade end retention preload and buckling remain HOLD
active_S2_C2.1 | S2-THERMAL | split thermal saddles and four axial caps | 1 | aluminium candidate | THERMAL_CALIBRATION_HOLD | C2-CAD | E2 |  | UNKNOWN | Generated split saddles/caps are integrated; measured UA fins fan duct and material temperature remain HOLD
active_S2_C2.1 | S2-THERMAL-IF | spreader conductive interface fins and segregated airflow | 1 | metal thermal path required | INTERFACE_AIRFLOW_CALIBRATION_HOLD | C2-REQ | E1 |  | UNKNOWN | Split saddles/caps exist; contact conductance measured UA fins and clean-side airflow remain HOLD
legacy_interface:S1 | BR-6205 | 6205 bearing boundary | 4 | Bearing steel | DATASHEET_BOUNDARY | https://www.nsk.com/engineering/6205-apn.html | C1_INTERFACE_BASELINE |  | UNKNOWN | Seal, clearance class and exact suffix must be selected. Bearing envelope is not solid steel in mass estimates.
legacy_interface:S1 | KEY-8-154 | Parallel key8x7x154 | 2 | C45 ground key stock | CUSTOM_DFM_HOLD | PPR-C1 original dimensional design; not an empirical qualification | C1_INTERFACE_BASELINE |  | UNKNOWN | Nominal key blank; stock/female-key fit and deburring to drawing review. No printed keys.
legacy_interface:S1 | KEY-8-16 | Parallel key8x7x16 | 1 | C45 ground key stock | CUSTOM_DFM_HOLD | PPR-C1 original dimensional design; not an empirical qualification | C1_INTERFACE_BASELINE |  | UNKNOWN | Nominal key blank; stock/female-key fit and deburring to drawing review. No printed keys.
legacy_interface:S1 | KEY-8-25 | Parallel key8x7x25 | 2 | C45 ground key stock | CUSTOM_DFM_HOLD | PPR-C1 original dimensional design; not an empirical qualification | C1_INTERFACE_BASELINE |  | UNKNOWN | Nominal key blank; stock/female-key fit and deburring to drawing review. No printed keys.
legacy_interface:S1 | S1-BPL | S1 bearing carrier | 2 | S355 steel | CUSTOM_DFM_HOLD | PPR-C1 original dimensional design; not an empirical qualification | C1_INTERFACE_BASELINE |  | UNKNOWN | Two 52 H7 seats at60.00 +/-0.02 centres. Line bore assembled metal carriers. Datums A face, B base, C left edge.
legacy_interface:S1 | S1-BR-CAP | Two-bearing retainer | 2 | S355 steel | CUSTOM_DFM_HOLD | PPR-C1 original dimensional design; not an empirical qualification | C1_INTERFACE_BASELINE |  | UNKNOWN | 47 mm inner abutment per NSK6205; four M6 through bolts share carrier pattern. No overlapping round caps.
legacy_interface:S1 | S1-CUT-A-P00 | S1 cutter A tooth phase 0 / common key datum | 1 | Tool steel, heat treatment RFQ | CUSTOM_DFM_HOLD | PPR-C1 original dimensional design; not an empirical qualification | C1_INTERFACE_BASELINE |  | UNKNOWN | Final thickness 6.00 +/-0.02; bore25 H7; key8 Js9. Cut blank then heat-treat/grind, edge hardening not a laser-as-cut assumption. Tooth phase 0.000000 deg; KEY REMAINS ZERO. Mark part phase before grinding.
legacy_interface:S1 | S1-CUT-A-P01 | S1 cutter A tooth phase 1 / common key datum | 1 | Tool steel, heat treatment RFQ | CUSTOM_DFM_HOLD | PPR-C1 original dimensional design; not an empirical qualification | C1_INTERFACE_BASELINE |  | UNKNOWN | Final thickness 6.00 +/-0.02; bore25 H7; key8 Js9. Cut blank then heat-treat/grind, edge hardening not a laser-as-cut assumption. Tooth phase 3.956044 deg; KEY REMAINS ZERO. Mark part phase before grinding.
legacy_interface:S1 | S1-CUT-A-P02 | S1 cutter A tooth phase 2 / common key datum | 1 | Tool steel, heat treatment RFQ | CUSTOM_DFM_HOLD | PPR-C1 original dimensional design; not an empirical qualification | C1_INTERFACE_BASELINE |  | UNKNOWN | Final thickness 6.00 +/-0.02; bore25 H7; key8 Js9. Cut blank then heat-treat/grind, edge hardening not a laser-as-cut assumption. Tooth phase 7.912088 deg; KEY REMAINS ZERO. Mark part phase before grinding.
legacy_interface:S1 | S1-CUT-A-P03 | S1 cutter A tooth phase 3 / common key datum | 1 | Tool steel, heat treatment RFQ | CUSTOM_DFM_HOLD | PPR-C1 original dimensional design; not an empirical qualification | C1_INTERFACE_BASELINE |  | UNKNOWN | Final thickness 6.00 +/-0.02; bore25 H7; key8 Js9. Cut blank then heat-treat/grind, edge hardening not a laser-as-cut assumption. Tooth phase 11.868132 deg; KEY REMAINS ZERO. Mark part phase before grinding.
legacy_interface:S1 | S1-CUT-A-P04 | S1 cutter A tooth phase 4 / common key datum | 1 | Tool steel, heat treatment RFQ | CUSTOM_DFM_HOLD | PPR-C1 original dimensional design; not an empirical qualification | C1_INTERFACE_BASELINE |  | UNKNOWN | Final thickness 6.00 +/-0.02; bore25 H7; key8 Js9. Cut blank then heat-treat/grind, edge hardening not a laser-as-cut assumption. Tooth phase 15.824176 deg; KEY REMAINS ZERO. Mark part phase before grinding.
legacy_interface:S1 | S1-CUT-A-P05 | S1 cutter A tooth phase 5 / common key datum | 1 | Tool steel, heat treatment RFQ | CUSTOM_DFM_HOLD | PPR-C1 original dimensional design; not an empirical qualification | C1_INTERFACE_BASELINE |  | UNKNOWN | Final thickness 6.00 +/-0.02; bore25 H7; key8 Js9. Cut blank then heat-treat/grind, edge hardening not a laser-as-cut assumption. Tooth phase 19.780220 deg; KEY REMAINS ZERO. Mark part phase before grinding.
legacy_interface:S1 | S1-CUT-A-P06 | S1 cutter A tooth phase 6 / common key datum | 1 | Tool steel, heat treatment RFQ | CUSTOM_DFM_HOLD | PPR-C1 original dimensional design; not an empirical qualification | C1_INTERFACE_BASELINE |  | UNKNOWN | Final thickness 6.00 +/-0.02; bore25 H7; key8 Js9. Cut blank then heat-treat/grind, edge hardening not a laser-as-cut assumption. Tooth phase 23.736264 deg; KEY REMAINS ZERO. Mark part phase before grinding.
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

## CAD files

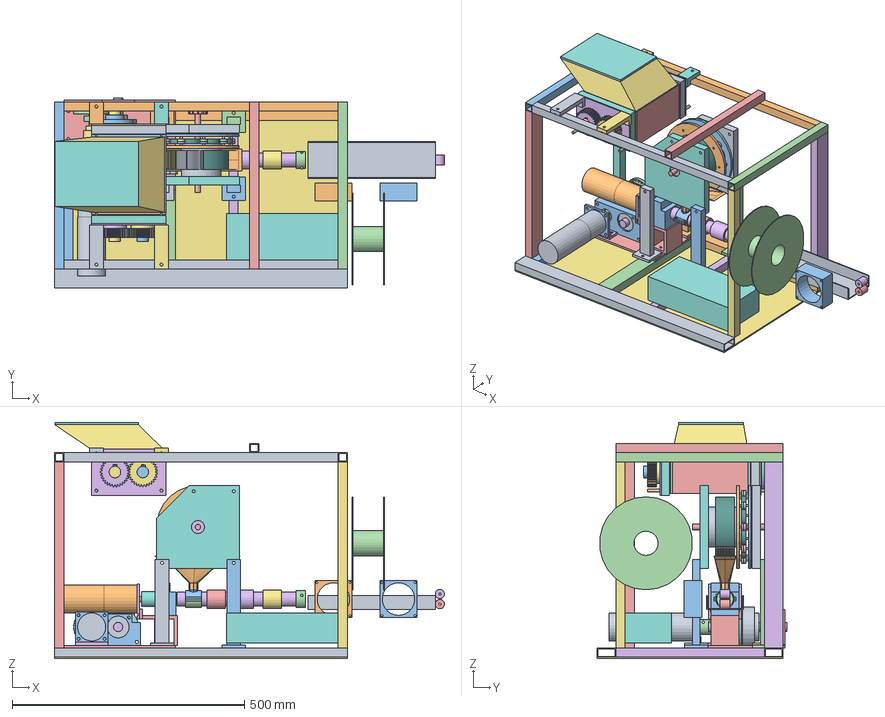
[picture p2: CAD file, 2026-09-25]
cad/PPR_C1_assembly.FCStd
838.9 x 408.0 x 508.0 mm
FR-2040-630_001
FR-2040-630_002
FR-2040-320_001
FR-2040-320_002
FR-2040-400_001
FR-2040-400_002
FR-2020-400_001
FR-2020-400_002
FR-2020-590_001
FR-2020-590_002
FR-2020-360_001
FR-2020-360_002
FR-2020-360_003
FR-2020-320_001
FR-BASE_001
EL-PSU_001
DRV-M1_001
DRV-M2_001
DRV-M1-PL_001
DRV-CPL12_001
DRV-IN-SHAFT_001
DRV-JACK_001
BR-6001_001
BR-6001_002
BR-6204_001
BR-6204_002
DRV-BFRONT_001
DRV-B12_001
DRV-B20_001
DRV-SH15R_001
DRV-SH15L_001
DRV_SH40L_lower
DRV_SH40R_upper
DRV-SP24-B20_001
DRV-SP24-B25_001
DRV-SP24-B12_001
DRV-SP12-B12_001
S1-CUT-A-P00_001
S1-SPACER-A_001
S1-CUT-A-P01_001
S1-SPACER-A_002
S1-CUT-A-P02_001
S1-SPACER-A_003
S1-CUT-A-P03_001
S1-SPACER-A_004
S1-CUT-A-P04_001
S1-SPACER-A_005
S1-CUT-A-P05_001
S1-SPACER-A_006
S1-CUT-A-P06_001
S1-SPACER-A_007
S1-CUT-A-P07_001
S1-SPACER-A_008
S1-CUT-A-P08_001
S1-SPACER-A_009
S1-CUT-A-P09_001
S1-SPACER-A_010
S1-CUT-A-P10_001
S1-SPACER-A_011
S1-CUT-A-P11_001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

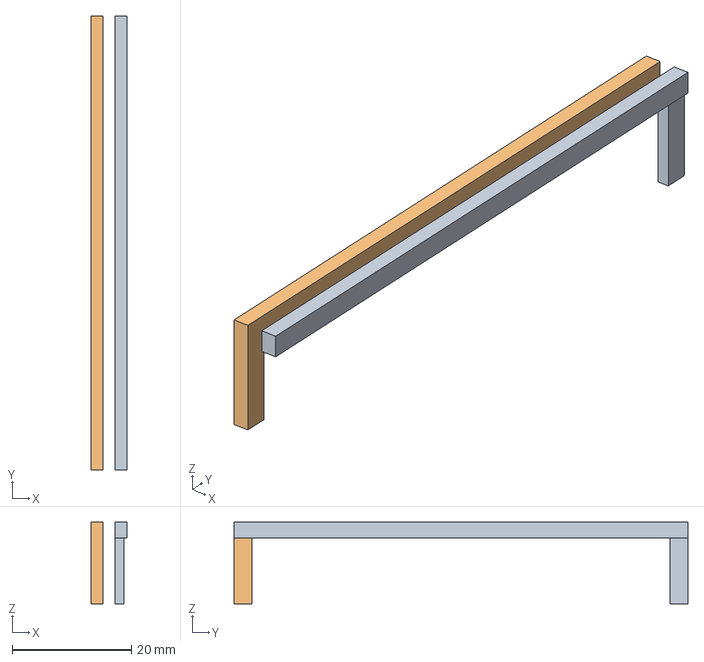
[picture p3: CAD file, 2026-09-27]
c2.1/cad/parts_stage1/GAUGE_FRAME.step
6.00 x 76.0 x 13.7 mm

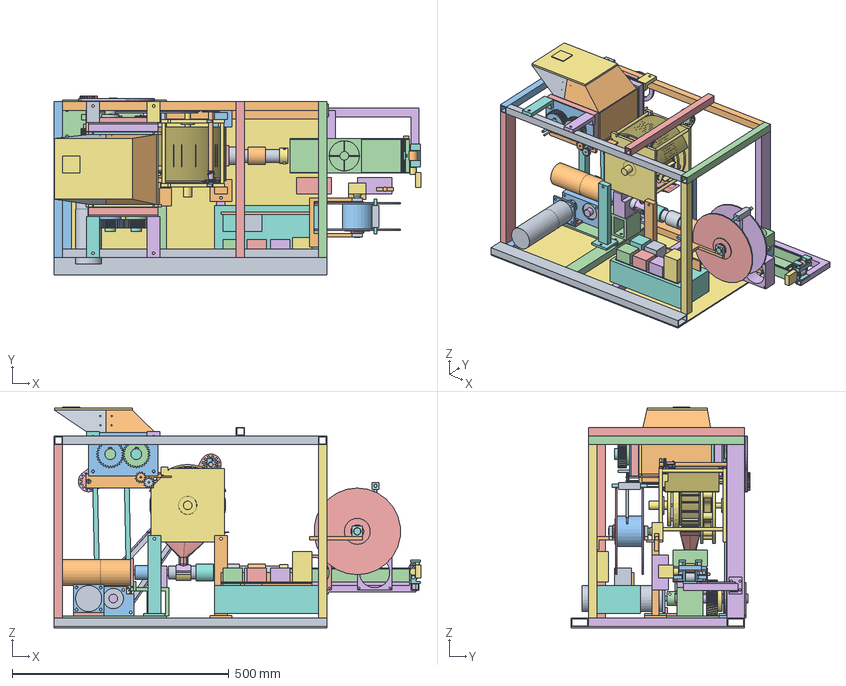
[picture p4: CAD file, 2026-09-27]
c2.1/cad/PPR_C2_1_machine_integration.FCStd
847.0 x 413.0 x 510.0 mm
FR-2040-630_001
FR-2040-630_002
FR-2040-320_001
FR-2040-320_002
FR-2040-400_001
FR-2040-400_002
FR-2020-400_001
FR-2020-400_002
FR-2020-590_001
FR-2020-590_002
FR-2020-360_001
FR-2020-360_002
FR-2020-360_003
FR-2020-320_001
FR-BASE_001
EL-PSU_001
DRV-M1_001
DRV-M2_001
DRV-M1-PL_001
DRV-CPL12_001
DRV-IN-SHAFT_001
DRV-JACK_001
BR-6001_001
BR-6001_002
BR-6204_001
BR-6204_002
DRV-BFRONT_001
DRV-B12_001
DRV-B20_001
DRV-SH15L_001
DRV_SH40R_upper
DRV-SP24-B20_001
DRV-SP24-B25_001
DRV-SP12-B12_001
S1-CUT-A-P00_001
S1-SPACER-A_001
S1-CUT-A-P01_001
S1-SPACER-A_002
S1-CUT-A-P02_001
S1-SPACER-A_003
S1-CUT-A-P03_001
S1-SPACER-A_004
S1-CUT-A-P04_001
S1-SPACER-A_005
S1-CUT-A-P05_001
S1-SPACER-A_006
S1-CUT-A-P06_001
S1-SPACER-A_007
S1-CUT-A-P07_001
S1-SPACER-A_008
S1-CUT-A-P08_001
S1-SPACER-A_009
S1-CUT-A-P09_001
S1-SPACER-A_010
S1-CUT-A-P10_001
S1-SPACER-A_011
S1-CUT-A-P11_001
S1-SPACER-A_012
S1-CUT-A-P12_001
S1-SHAFT-A_001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

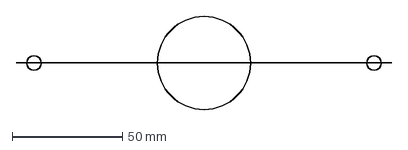
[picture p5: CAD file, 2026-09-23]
c2.1/drawings/rear_support_plate.dxf
170.0 x 42.2 mm

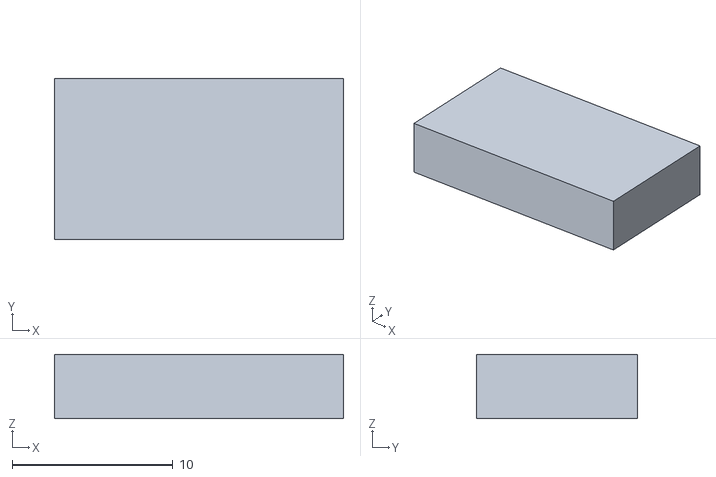
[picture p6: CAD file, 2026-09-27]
c2.2/sim/assets/out/full/PULL_NIP_STOP_step259__coarse.stl
18.0 x 10.0 x 4.00

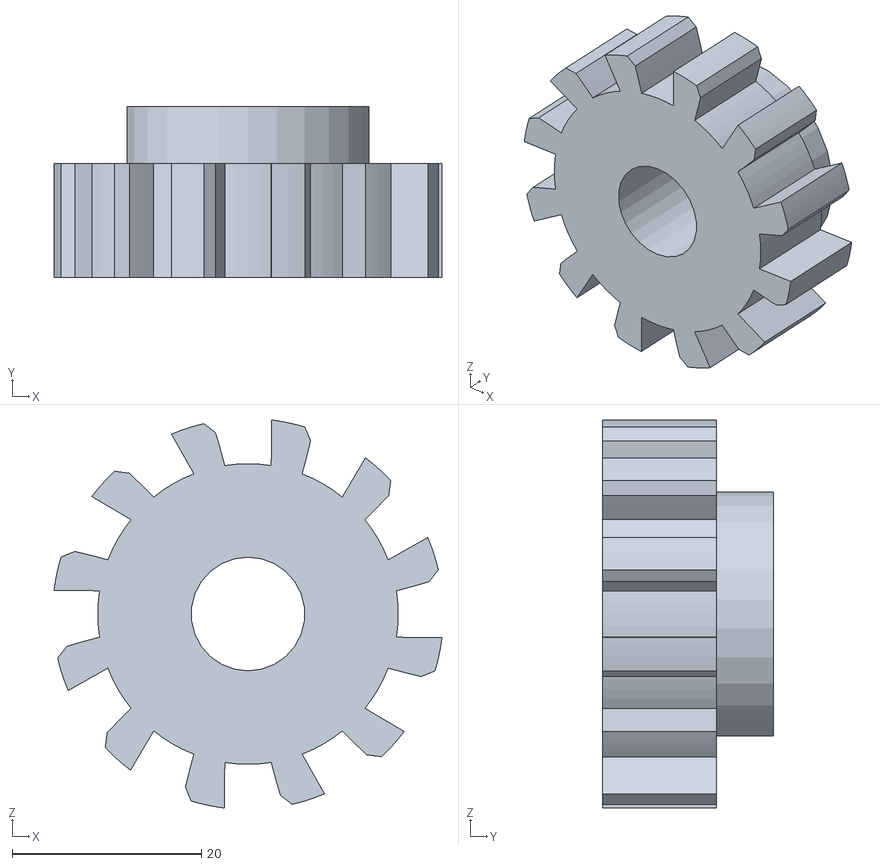
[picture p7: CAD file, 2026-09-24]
c2.2/sim/assets/out/PDL_SPROCKET__coarse.stl
41.0 x 18.0 x 41.0

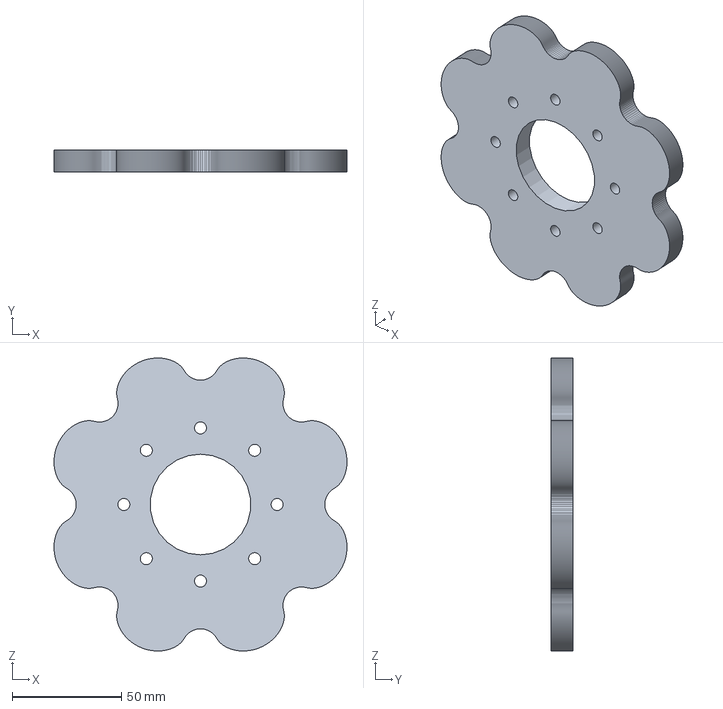
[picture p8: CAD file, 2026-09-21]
c2/cad/GUIDE_STUDY_C1-SEED.step
133.9 x 10.0 x 133.9 mm

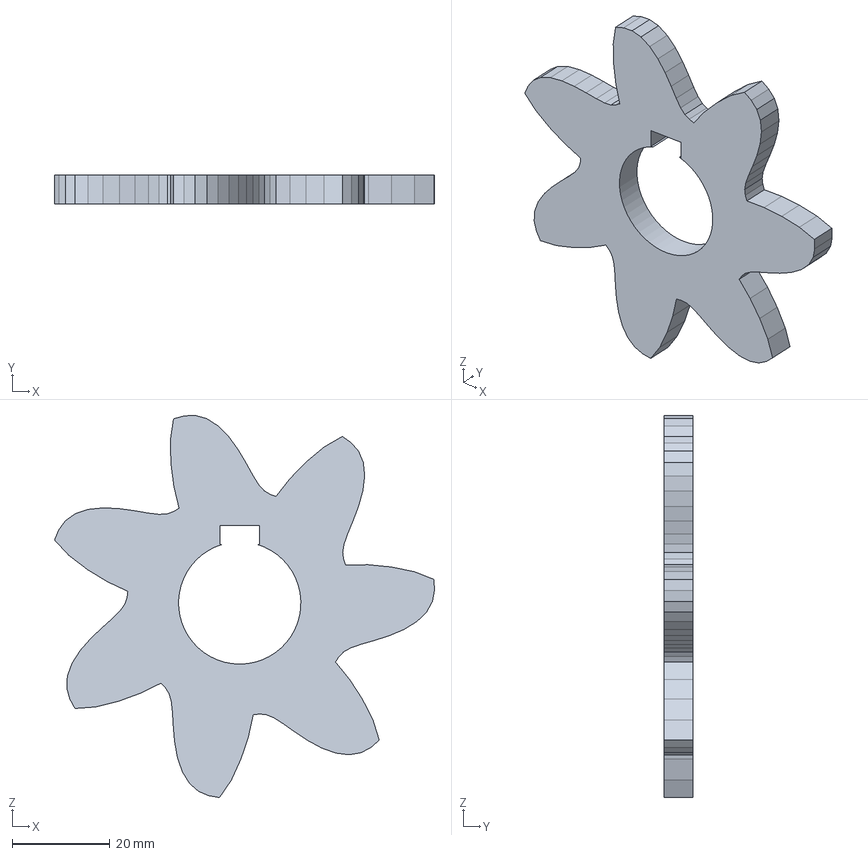
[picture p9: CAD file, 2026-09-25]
cad/parts/S1-CUT-A-P05.step
77.7 x 6.00 x 78.1 mm

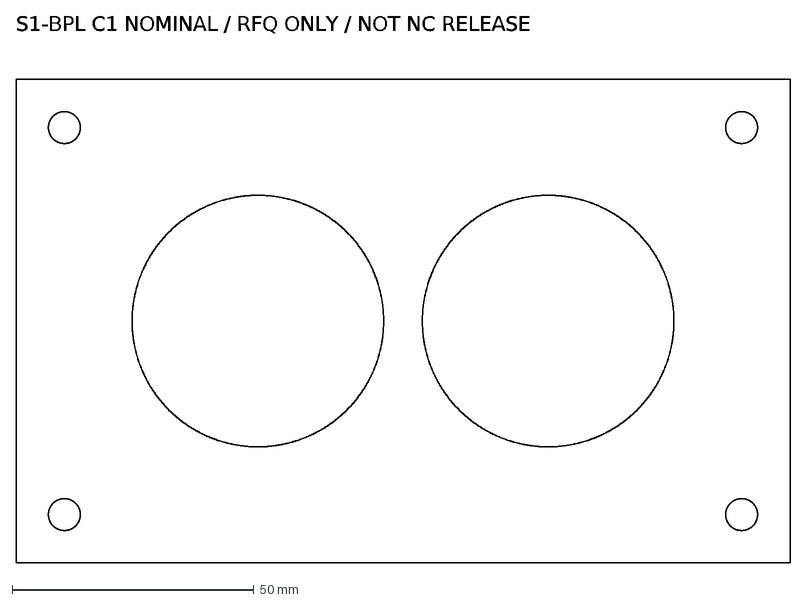
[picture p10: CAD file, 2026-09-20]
drawings/S1-BPL.dxf
S1-BPL C1 NOMINAL / RFQ ONLY / NOT NC RELEASE

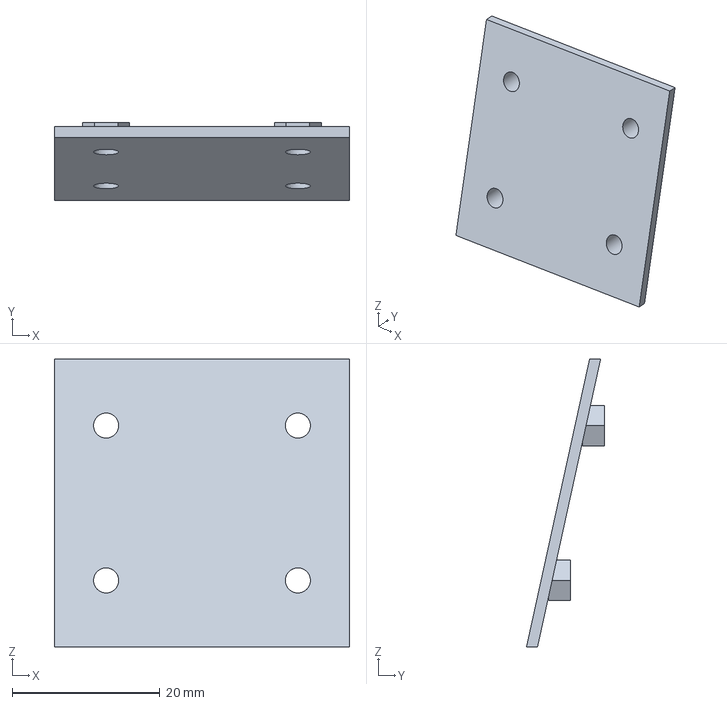
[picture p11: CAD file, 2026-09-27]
c2.1/cad/parts_stage1/HOPPER_SEAM_FRONT.step
40.0 x 10.6 x 39.0 mm

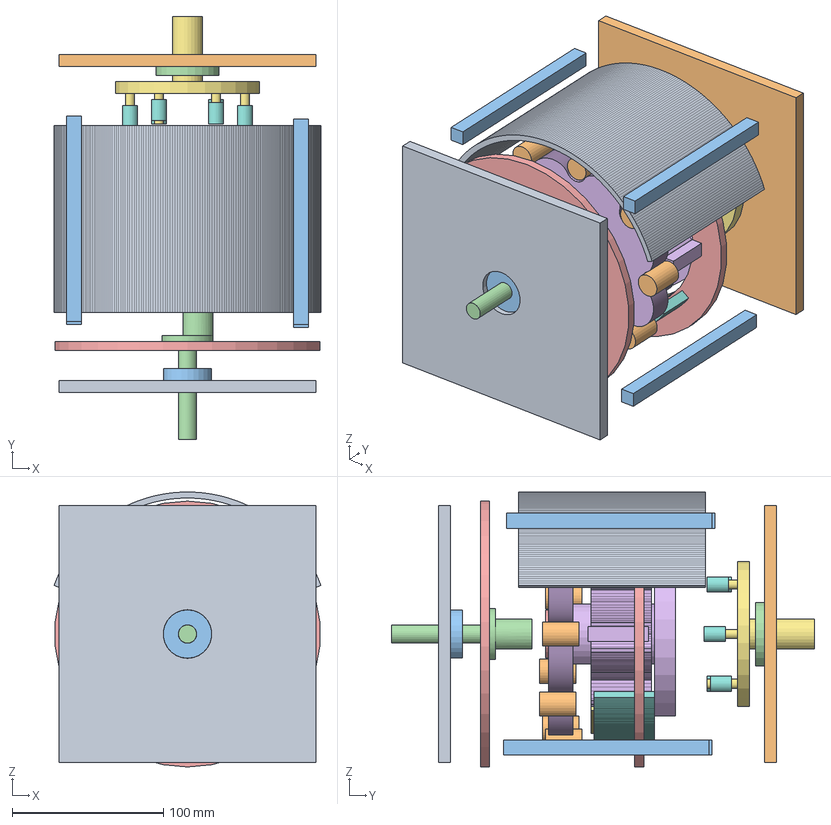
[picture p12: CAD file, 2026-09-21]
c2.1/cad/PPR_C2_1_S2_transmission_exploded.step
176.7 x 280.0 x 182.0 mm
FRONT_INPUT_SUPPORT
REAR_OUTPUT_SUPPORT
INPUT_BEARING_ENVELOPE_UNRATED
OUTPUT_BEARING_ENVELOPE_UNRATED
FRONT_FIXED_RING_PLATE
REAR_FIXED_RING_PLATE
FIXED_SHEAR_INSERT_HOLD
SCREEN_SOLID_ENVELOPE_HOLD
THERMAL_SPREADER_ENVELOPE_HOLD
GUARD_SECTION_ENVELOPE_HOLD
FIXED_RING_PIN_1
FIXED_RING_PIN_2
FIXED_RING_PIN_3
FIXED_RING_PIN_4
FIXED_RING_PIN_5
FIXED_RING_PIN_6
FIXED_RING_PIN_7
FIXED_RING_PIN_8
FIXED_RING_PIN_9
SUPPORT_TIE_1
SUPPORT_TIE_2
SUPPORT_TIE_3
SUPPORT_TIE_4
INPUT_ECCENTRIC_SHAFT
ECCENTRIC_BEARING_ENVELOPE_UNRATED
RIGID_CYCLOID_HOOK_ROTOR_ENVELOPE
OUTPUT_PIN_CARRIER_AND_SHAFT
OUTPUT_ROLLER_1
OUTPUT_ROLLER_2
OUTPUT_ROLLER_3
OUTPUT_ROLLER_4
OUTPUT_ROLLER_5
OUTPUT_ROLLER_6

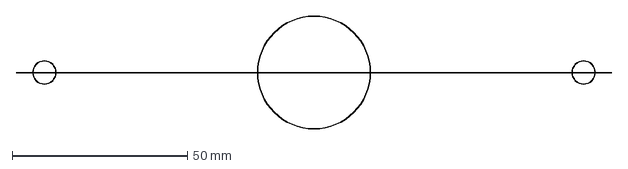
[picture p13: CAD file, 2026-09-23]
c2.1/drawings/front_support_plate.dxf
170.0 x 32.2 mm

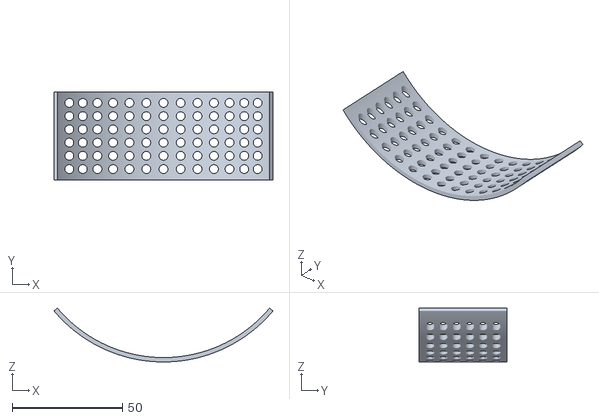
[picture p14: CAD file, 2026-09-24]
c2.2/sim/assets/out/c2_vertical_discharge_screen__fine.stl
99.3 x 40.0 x 24.4

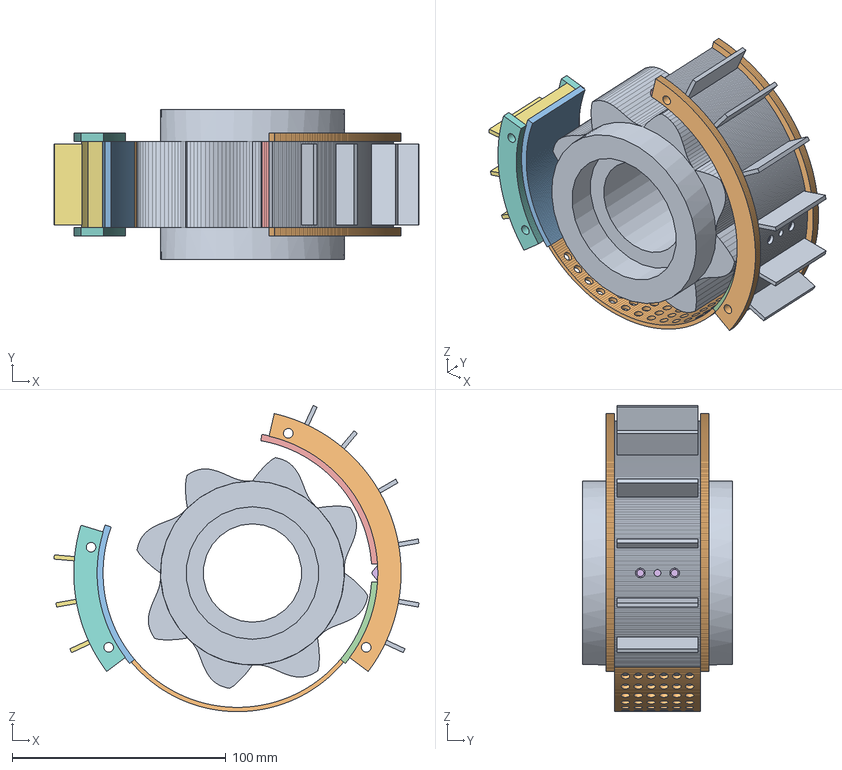
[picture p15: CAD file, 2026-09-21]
c2/cad/PPR_C2_S2_thermal_development.step
170.6 x 70.0 x 143.2 mm

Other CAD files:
c2.2/sim/assets/out/full/PULL_NIP_STOP_step257__coarse.stl
cad/parts/FR-2040-400.step
drawings/S1-CUT-A-P11.dxf
c2.1/cad/parts_stage1/WIND_SPOOL_DRUM.step
c2.1/cad/PPR_C2_1_S2_transmission.step
c2.1/cad/parts_stage1/AUG_BEARINGS.step
c2.1/cad/parts_stage1/AUG_SHAFT.step
c2.1/cad/parts_stage1/AUG_WHEEL.step
c2.1/cad/parts_stage1/CHUTE_BODY.step
c2.1/cad/parts_stage1/CHUTE_GUIDE_L.step
c2.1/cad/parts_stage1/CHUTE_GUIDE_R.step
c2.1/cad/parts_stage1/CHUTE_LIP_WEST.step
c2.1/cad/parts_stage1/CHUTE_PAN_FLOOR.step
c2.1/cad/parts_stage1/CHUTE_TROUGH_FLOOR.step
c2.1/cad/parts_stage1/CHUTE_TROUGH_FLOOR_E.step
c2.1/cad/parts_stage1/CHUTE_TROUGH_WALL_L.step
c2.1/cad/parts_stage1/CHUTE_TROUGH_WALL_R_E.step
c2.1/cad/parts_stage1/CHUTE_TROUGH_WALL_R_W.step
c2.1/cad/parts_stage1/CHUTE_WALL_FRONT.step
c2.1/cad/parts_stage1/CHUTE_WALL_REAR.step
c2.1/cad/parts_stage1/COOL-DUCT.step
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

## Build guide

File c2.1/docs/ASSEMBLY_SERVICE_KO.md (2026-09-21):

# C2.1 전체 기계 조립·정비·시험 절차

## 적용 경계

이 문서는 C2.1 디지털 제작 검토 패키지용이다. `PPR_C2_1_machine_integration.FCStd`와 STEP은 C1 인터페이스 기준에서 기존 S2 44개 인스턴스를 제거하고 C2.1 S2 41개 객체를 넣은 결과다. 디지털 조립체는 196 solid 재수입, 변경 인터페이스의 양의 체적 관통 0건, 본체 630×408×508mm와 운전 envelope 839×408×508mm를 확인했다. 하중 변형·공차·열팽창·정비 동작 중 연속 충돌과 물리 조립은 확인하지 않았다.

C2.1 S2 로컬 좌표는 Z축 180도 회전 후 `(308.569464689, 299, 280)mm`로 이동한다. 이때 process 구간은 기계 Y=255..295mm이고 입력축은 X=308.569mm, Z=280mm에서 기존 ANSI35 12T 기준과 동축이다. 네 S2 금속 다리는 Y=170mm와 342mm의 지지판 접촉면으로 이동한다.

## 조립 순서

1. 전원과 모든 에너지원을 분리하고 개인 잠금표찰을 적용한다. 테이블·알루미늄 프로파일·금속 다리의 수평, 대각, 체결면 손상을 먼저 검사한다.
2. S1 cartridge와 보존된 drive 기준을 설치하되 축·sprocket을 최종 부품으로 간주하지 않는다. 입력축 동축도와 S1 여유를 실측하기 전 shim 또는 가공량을 확정하지 않는다.
3. 전후 C2.1 지지판과 고정 링, Ø8×140 명목 tie rod를 가조립한다. 베어링 MPN·fit·shoulder/circlip, 반력판 소재와 fastener grade/preload가 확정될 때까지 절삭·압입·최종 토크를 금지한다.
4. C2.1 rotor/process stack, 4mm perforated screen reference, split wear shell, thermal saddle/cap, output carrier를 조립성 확인용으로 배치한다. blade clearance는 출력 공차가 아니라 금속 shim으로 조절한다.
5. hopper/짧은 chute와 buffer를 연결하고 bridging 제거 접근로를 확인한다. 손이 절삭부에 닿는 개구는 anti-reach 검증 전 폐쇄한다.
6. 수평 extruder screw/barrel/die, thrust path, heater와 단열, cooling, diameter 측정 위치, puller와 spool을 순서대로 배치한다. 각 하중 경로는 금속 부품에서 bearing/plate, profile, table로 이어져야 한다.
7. 보호접지를 frame/guard/barrel/motor frame에 먼저 연결한다. 그 뒤 branch fuse, 안전 contactor, dual-channel E-stop/lid/service interlock, 독립 manual-reset overtemperature, one-shot thermal fuse, driver와 sensor harness를 배선한다. MCU는 안전 차단의 유일 수단이 아니다.
8. guard·배선·호스의 정비 sweep를 확인하고 마지막에 동력부 cover를 설치한다. 현재 CAD의 guard는 containment 인증 형상이 아니므로 제작 승인 대상이 아니다.

## 정비와 잠금

정지 명령만으로 접근하지 않는다. 주 전원 분리, 잔류 전압 확인, 회전체 정지, heater 냉각, 압출 잔압 제거, 개인 잠금표찰의 순서를 지킨다. screen 청소, jam 제거, blade/shim 조정, sensor 교체에는 shaft의 물리적 회전 방지와 heater 회로 격리가 모두 필요하다. 잠금 해제 전 공구·shim·시편 수량, guard, PE, interlock actuator와 독립 과온 복귀 상태를 2인 확인한다. 자동 재시작과 역회전 경로는 허용하지 않는다.

## 단계별 실제 시험

모든 시험은 현재 `DID_NOT_RUN`이다. 정확한 부품과 한계값이 정해진 뒤 위험성 평가와 사용자 승인을 받아 순서대로 수행한다.

1. 무통전 치수검사: 부품 라벨, 재질 증명, 축경, bore, bearing fit, runout/TIR, blade shim gap, fastener engagement, 접지 연속성의 원자료를 기록한다. 불일치는 가공으로 숨기지 않는다.
2. 안전회로 단독 저에너지 시험: 각 E-stop/lid/service 채널의 단선·교차단락, EDM, manual reset, 독립 과온, one-shot fuse 회로를 시험한다. 어떤 단일 fault에서도 contactor가 재투입되거나 자동 시작하면 FAIL이다.
3. actuator 분리 상태 I/O 시험: sensor open/short/stale, fan tach loss, current/rpm mismatch, buffer high를 주입한다. 출력은 fail-closed여야 하며 reset만으로 구동이 시작되면 FAIL이다.
4. 수동 회전 시험: lockout 상태에서 전 주기 간섭, screen/rotor, output pin/window, seal과 shaft retention을 확인한다. binding, 금속 접촉, axial migration은 FAIL이다.
5. 제한 전원 무부하 시험: 정격이 확정된 fuse/current limit 아래에서 짧은 단계로 수행하고 전류·rpm·진동·온도 원자료를 저장한다. guard와 원격 차단 없이 실행하지 않는다.
6. 열 시험: PLA, PET, TPU를 혼합하지 않고 건조 조건·질량·주변온도를 기록한다. 여섯 온도 채널, motor/gearbox, fan curve, 외벽·방열판 온도와 sensor delay를 보정한다. 독립 과온 차단을 실제 확인한다.
7. 재료 시험: 교체식 coupon부터 시작해 투입/회수 질량, 2.5~5mm 질량수율, oversize/fines/sliver, throughput, torque/current/rpm, jam, 체류시간, J/g를 원자료로 남긴다. 100g/h와 목표 입도는 실측 전 보장값이 아니다.

각 단계의 합격값은 선정 부품 datasheet와 위험성 평가가 정한 뒤 `OPEN_ACTIONS_KO.md`를 갱신한다. 앞 단계 실패 시 다음 단계로 진행하지 않는다.

## 현재 금지 사항

구매·외주 발주·가공·통전·구동·target firmware flash·main 병합은 승인되지 않았다. RFQ 도면의 치수는 명목값이며 datum, fit, GD&T, 공차, 소재 grade, 열처리, 표면처리는 HOLD다. KiCad 자료는 기능 net 일관성 자료이고 MPN/제조사 terminal 번호/정격이 없어 제작 회로 검증이 아니다.

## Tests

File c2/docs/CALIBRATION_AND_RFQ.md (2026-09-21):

# C2 calibration and procurement closure

## Do not order from this file
Motor model, size/shaft custom options, driver, safety ratings and loaded transmission are unselected.100,000KRW is a whole-system soft ceiling, not a motor allowance. Unknown manufacture/shipping cost must remain unknown.

## Motor/driver quotation fields
Exact MPN and winding;24V;one-piece delivered price to Korea;tax/shipping/MOQ;shaft length and fit;mount drawing;continuous torque versus speed;duty and winding/case limits;winding resistance/current convention;Hall angle;driver peak and continuous phase/bus currents;hardware current clamp;locked-rotor operation;reverse sequencing;regenerative energy handling;encoder option;allowable belt/gear radial load;warranty and data source.

## Material evidence before breakage optimization
For each of PLA/PET/TPU: grade/brand, lot, aging/recycling history, hardness for TPU, moisture/conditioning, print orientation/layer height/infill, initial flake maximum caliper/equivalent diameter/minimum thickness, mass-based distributions, sample size and repeats. Do not mix PETG with PET.

Test sequence: S1 feed distribution; low-energy single-edge cut force-displacement at controlled temperature; friction/relaxation and elastic rebound; repeat cycles including nonfracturing deformation; metal and outlet thermal step response; mechanically guarded low-load S2 run. Electrical/mechanical commissioning must be separately authorized and physically supervised.

Each record requires trace files, units and sampling rates, synchronized encoder and torque/current, coupon/fixture dimensions, material grade/lot, actuator/force-sensor calibration, independent calibration-validation IDs, CAD revision and hashes. Motor current alone is not a calibrated torque sensor without a tested motor/gear loss map.

## Job queue meaning
`dem_job_manifest.json` contains144 UNSUBMITTED jobs:48 diverse geometries x3 materials. Pending IDs and NULL outputs are intentional. Some geometries require an alternative self-rotation constraint; ideal prescribed-motion DEM can explore a candidate before mechanism closure, but it cannot prove the mechanism is buildable.

No actual DEM breakage solver invocation, no physical coupon experiment, and no performance model training were performed in C2.0. Kinematic/CAD/thermal sensitivity and reference-control tests are separate evidence classes.

## Cost reduction order
Reuse confirmed stock first; combine functions and simplify manufacturable metal parts second; compare motor+driver+gearbox combinations third. Do not delete blade containment, safety interlocks, overtemperature cutoff, qualified mains/DC protection or appropriate material preparation to make a spreadsheet total fit.

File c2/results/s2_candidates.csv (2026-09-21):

candidate_id | tip_mm | width_mm | eccentric_mm | gap_mm | hook_depth_mm | hooks | ratio_denominator | orbit_rpm | screen_hole_mm | screen_thickness_mm | screen_arc_deg | rising_fraction | shear_ratio | chamber_mm | min_eccentric_sleeve_od_mm | root_web_mm | pin_pitch_radius_screen_mm | pin_plate_od_screen_mm | compact_pin_family_possible | compact_pin_limit_mm | kinematic_geometry_feasible | mechanism_status | bearing_status | reject_reasons | sampled_gap_mm
C1-SEED | 110.0 | 40.0 | 7.0 | 0.8 | 12.0 | 8 | 8 | 116.0 | 4.0 | 2.0 | 100.0 | 0.72 | 5.333333333333333 | 125.6 | 32.0 | 12.0 | 69.30000000000001 | 164.60000000000002 | True | 178 | True | PROFILE_CONTACT_CHECK_REQUIRED | NOMINAL_BOUNDARY_NOT_APPROVED_MPN |  | 0.800002992532022
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

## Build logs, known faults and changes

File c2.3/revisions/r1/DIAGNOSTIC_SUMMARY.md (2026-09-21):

# C2.3-R1 Diagnostic Summary — Goal R0 D0–D4 (diagnostics, NOT convergence)

> Scope: Goal R0 §4 D0–D4 + §5 scene/asset evidence + §6 handoff inputs.
> R0 is diagnostics: executor terminal labels IMPLEMENTED / BLOCKED / FAILED
> only. D0–D4 verdicts below are diagnostic outcomes, never phase acceptance.
> Thresholds frozen at R1 (work 5%, impulse 5%, residence 10%, discrete 10%,
> mass 1e-6 relative) apply ONLY to valid + observable + comparable
> quantities; threshold values unchanged throughout R0.
> Backend: ISAAC_PHYSX, Isaac Sim 6.1.0.0 via `$HOME/env_isaacsim-c22`
> (python 3.12). Runtime `__version__` query → UNKNOWN (attribute absent, no
> error); build `6.1.0-rc.26+release.49347.2d230af4.gl` from VERSION file +
> pip metadata `isaacsim-core 6.1.0.0`. All scenes DIAGNOSTIC_FIXTURE with
> export + sha256 per run (R6).

## Outcomes table (exact numbers from `c2.3/revisions/r1/runs/`)

| ID | Diagnostic | Outcome (exact) |
|----|---|---|
| D0 | Clock + 2.4 s horizon (`diag/d0_clock.py`, aggregate `runs/d0_clock.json`) | 4/4 IMPLEMENTED. Observed durations: 2.4 / 2.4 / 2.4000000000000004 / 2.4 s; substeps 240 / 480 / 960 / 1920 dense (n0+1..n1 contiguous, dedup by physics step); callback dt readbacks [0.009999999776] / [0.004999999888] / [0.002499999944] / [0.001249999972] s (float32-quantized, within 1e-6 relative). Warmup 120 steps excluded identically, t0 included. Advance path: `SimulationManager.step(steps=1)` = exactly 1 physics step/call; `sim.update()` is render-driven (3–5 steps/call) and not used as clock. |
| D1 | Contact units + isolation (`diag/d1_contact.py`, aggregate `runs/d1_contact.json`) | 8/8 IMPLEMENTED. Support (m = 2 kg, T = 1.0 s, mgT = 19.62 N·s): J = 19.61999943 / 19.61999966 / 19.61999886 / 19.61999863 N·s; rel err 2.88e-08 / 1.71e-08 / 5.82e-08 / 6.98e-08 (≪ 5% after settling, per-step callback capture). No-contact: 0.0 N·s at all 4 dts (≤ 1e-6). Unit rule: raw impulse = VECTOR [N·s], sum \|J\| ONCE; F[N] = \|J\|/dt_contact; never × dt twice. Invalid/stale/missing/overflow invalidates (never except-to-zero). Ground forces labeled support_*, never cutter. |
| D2 | Torque/work semantics (`diag/d2_torque.py`, `diag/test_r02_units.py`, aggregate `runs/d2_torque.json`) | Analytic 16/16 IMPLEMENTED (radial→0, tangential→R·F, reversal flips, opposites cancel, off-axis origin, separate shafts, stationary→0, dissipative ≤ 0, sign-on-body, ground-zero-cutter). Isaac negative control 4/4 IMPLEMENTED: cutter/shaft work exactly 0.0 J at every dt with J_support ≈ 19.62 N·s. tau_contact = dot(Σ cross(p−o, F_on_shaft), a), shaft contacts only, action-reaction signs, counter-rotating shafts separate. Dynamic-shaft drive torque UNAVAILABLE (no joint/drive readout — stated, not estimated). PARTIAL ledger, residual_unclassified (never heat/fracture). |
| D3 | Two-body coupling causality (`diag/d3_bond.py`, aggregate `runs/d3_bond.json`) | IMPLEMENTED. SAME differential loading (B-only +4 N x, dt 0.005, T = 1.0 s): intact dx_final = 0.0 m / Fmean ≈ 2.0 N / 1 component; disconnected dx_final = 2.756498 m / Fmean ≈ 0.0 N / 2 components; timed-disable (SetActive(False) step 66 @ 0.5 s) dx_final = 0.917998 m / Fmean ≈ 0.65 N / 2 components. Separations: \|dx\| 2.756 > 0.05 m; \|F\| 2.0 > 0.5 N. Atomic count (2) separate from components. Constraint: USD PhysicsFixedJoint; NOT a fracture law, no PLA fitting. No counter-based bond code path. |
| D4 | Observability/accounting (`diag/d4_accounting.py`, aggregates `runs/d4_accounting.json`) | IMPLEMENTED. Nominal: intended 3.5 (= 0.5 × design 7.0 kg) vs instantiated 3.5 kg; unexplained 0.0; rel 0.0 ≤ 1e-6 (float64, sorted-ID sequential sum, \|a−b\|/max(\|a\|,1e-30)). Fault injection 3/3 DETECTED: disappearance (enabled [A,B] ≠ [A,B,C]), duplicate (B-twice beyond 1e-6), altered mass (B 2.0→2.5 kg readback mismatch). Statuses: wrap (null, NOT_IMPLEMENTED); passage (null, NOT_APPLICABLE); residence (null, RIGHT_CENSORED); motor-jam (NOT_OBSERVABLE, no flag); unavailable comparison → NOT_EVALUABLE. Buckets disjoint, deficit never zeroed. |

## Root causes fixed from C2.3-A (→ R1 clauses)

- Equal-steps confound (240 steps every dt → durations 2.4/1.2/0.6/0.3 s) → R1 equal MEASURED 2.4 s, substeps 240/480/960/1920; legacy 12-run ladder superseded, not reused (R1 §5; D0 proves the mapping).
- Scalar R×Σ\|F\| torque/impulse as evidence → R2 raw typed telemetry only; legacy series diagnostics-only (D1 unit rule + D2 negative control).
- Missing-event defaults (incl. vacuous jam/wrap-identity) → R3 null + status; jam NOT observable; residence right-censored (D4 statuses).
- Algebraic mass identity → R4 runtime actor/material buckets, forced-zero prohibited, 1e-6 + float handling (D4 ledger).
- Bare-counter bonds → R5 mechanically-coupled diagnostic only, intact/disconnected/timed-disable (D3 FixedJoint triple).
- Reference CAD hash as evidence → R6 scene export + hash per run (all 16 D0–D2 + 4 D3/D4 runs carry scene.usda + scene.sha256).

## Remaining blockers (reviewer authorization required — executor cannot clear)

1. The frozen-state 12-run convergence ladder was NOT rerun under R1 (equal measured 2.4 s + typed telemetry + R3/R4/R5 evidence path). A3 artifacts remain legacy equal-steps evidence and MUST NOT be cited for convergence. Rerun needs reviewer authorization.
2. WRAP strand sensing: no strand metric exists (wrap stays null / NOT_IMPLEMENTED until a sensing path is authorized).
3. Dynamic-shaft effort readout: no joint/drive torque path on the kinematic-pose rig (EffortSensor on fixed joint reads invalid); drive torque stays UNAVAILABLE.
4. `import isaacsim; __version__` → UNKNOWN (attribute absent). Version pinned via pip metadata + VERSION file + per-run module paths instead.
5. Pre-existing A4 verifier scope: `c2.3/verify/verify_contract.py` + `c2.3/tests/test_verify.py::test_clean_tree_is_consistent` check the A1 baseline_manifest hashes of `c2.3/STATE.json` + `c2.3/NEXT.md`, which the authorized R0.1 progress update changed (hash mismatch, verifier exit 1). This is a stale-scope finding, not an R1 defect; the verifier still checks all A3 run hashes, mass/work recomputes, ladder, and banned labels. No threshold, baseline, or run artifact was touched.

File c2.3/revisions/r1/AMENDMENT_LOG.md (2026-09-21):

# Amendment Log — CONTRACT (superseded) → CONTRACT_R1 (Goal R0 §2)

> The file `c2.3/CONTRACT.md` is SUPERSEDED as a normative document and preserved
> unmodified as a historical record. Normative authority moves to
> `c2.3/revisions/r1/CONTRACT_R1.md` on reviewer authorization.
> No threshold was relaxed: all numeric thresholds are unchanged. R1 narrows
> *applicability* to valid + observable + comparable quantities and replaces
> unenforceable or confounded clauses with implementable ones.

| # | Old CONTRACT clause | R1 clause | Reason |
|---|---|---|---|
| A1 | §5 equal steps-per-run (240 steps at every dt; physics duration 2.4 / 1.2 / 0.6 / 0.3 s varies by dt) | CONTRACT_R1 §5: equal MEASURED 2.4 s; per-dt substeps 240 / 480 / 960 / 1920; engine-reported time + callback step ID/dt required (R1) | Equal steps confound resolution with duration, so cross-dt comparison was inadmissible. The legacy equal-steps 12-run ladder is superseded and MUST NOT be reused as convergence evidence. |
| A2 | §6 metrics shaft work / contact impulse computed from tau = CUTTER_R_M × sum\|F_contact\| (CONTACT_DERIVED_MOMENT_ARM, UNCALIBRATED) | R2: correctly typed raw contact/joint telemetry as the only admissible source; legacy scalar estimates diagnostic-only (CONTRACT_R1 §4, §6, §7) | Derived torque was never measured; unmeasured estimates cannot ground evidence. Work/impulse thresholds (5%) now apply only to integrals from raw typed telemetry. |
| A3 | §7 mass conservation as an algebraic identity (relative mass_error <= 1e-6) with a STOP-if-impossible escape | R4: runtime actor/material accounting with buckets active / output / removed / missing; unexplained-deficit forced-zero prohibited; 1e-6 relative tolerance with explicit float handling (CONTRACT_R1 §7, §8) | An algebraic identity without runtime accounting is unenforceable and invites forced closure. Threshold value unchanged. |
| A4 | Missing-event handling by default flags, incl. §7 "jam/wrap identical across primary pair" | R3: null + observability status — wrap null / NOT_IMPLEMENTED, screen transit null / NOT_APPLICABLE, residence right-censored, jam NOT observable (CONTRACT_R1 §7, §8) | Defaults fabricate observability; an "identical" verdict on unobserved flags is vacuous. The flag-identity rule is retired, not relaxed: there is no observed pair to compare. |
| A5 | `configs/baseline.json` reference_assets STEP/USD hashes standing as scene provenance | R6: scene export + hash mandatory per run; reference CAD hash is provenance-only, never run evidence (CONTRACT_R1 §9, §10) | Reference hashes attest inputs, never the executed scene. |
| A6 | Break/fragment accounting via bare cumulative counters (breaks_cum / bonds_alive) feeding the §7 10% rule | R5: minimal mechanically-coupled bond diagnostic only — joint- or conservative-force-coupled representation, conditions intact / disconnected / timed-disable; counter-only prohibited (CONTRACT_R1 §6, §7) | Bare counters carry no mechanical coupling. The 10% value is unchanged and now applies only to coupled diagnostic counts that are observable and comparable. |
| A7 | §7–§8 thresholds stated without applicability conditions | CONTRACT_R1 §8 + REQUIREMENTS_EVIDENCE.md: thresholds apply ONLY to valid + observable + comparable quantities; null / censored / NOT_IMPLEMENTED / NOT_APPLICABLE / diagnostic-only data excluded | Prevents vacuous or misleading comparisons on data that was never observed. No numeric change. |

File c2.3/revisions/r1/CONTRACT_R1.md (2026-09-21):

# C2.3 CONTRACT R1 — Numerical Reliability Closure (Goal R0 §2, full implementation)

> Status: draft revision R1 under checkpoint R0.1; normative on reviewer authorization.
> Supersedes `c2.3/CONTRACT.md` as the normative document; that file is preserved
> unmodified as a historical record and is no longer normative.
> Authorized phase: **R0 only**. Executor: Muse Spark 1.3 / OMP Vibe.
> Executor holds NO determination authority. Terminal phase judgment rests solely
> with the reviewer. Executor terminal labels are restricted to
> IMPLEMENTED / BLOCKED / FAILED only; any other terminal-standing vocabulary for
> the phase or its artifacts is prohibited.
> Thresholds frozen at R1 — no threshold edit without reviewer authorization
> recorded as a new revision. If this contract misstates Goal R0 §2 or any frozen
> baseline value, the executor MUST STOP and report BLOCKED instead of proceeding.

## 1. Authorized scope

- Phase R0 = Goal R0 §2 numerical reliability closure: Isaac/PhysX timestep
  convergence + mechanical energy accounting. No other phase is authorized.
- Required backend: **ISAAC_PHYSX** — Isaac Sim 6.1.0.0 via `$HOME/env_isaacsim-c22`
  (PhysX). Any non-PhysX substitute is a proxy and is banned (§4).

## 2. Reviewer policy

- Reviewer holds sole authority for terminal judgment and acceptance.
- Executor never self-assigns terminal standing.

## 3. Frozen baseline (BASELINE ONLY — never optimal)

- S1-A: twin-shaft hook shear, 40 rpm counter-rotating.
- S2-A: q=8, e=7 mm, input +120 rpm / output −15 rpm, phi = −theta/q.
- Cutter gap 0.8 mm — BASELINE ONLY (never optimal, no optimization).
- Screen aperture 4.0 mm — BASELINE ONLY (never optimal, no optimization).
- Waste cases (frozen):
  - FDM = W1 PLA seed 7.
  - PURGE = W4 PLA seed 11.
  - WRAP = P0 seed 7 — S1-only, no S2 fracture claim.
- impulse_scale = 0.02 N·s — UNCALIBRATED assumption, frozen for R0.
- Friction / gravity / solver iterations: frozen at C2.2 dynamics defaults;
  any change requires a contract amendment by the reviewer before use.
- Initial poses: frozen per-case (S1 nip-drop placement; S2 drop above
  screen plane); identical handoff states feed S2-A/S2-B comparisons.
- `c2.3/STATE.json` is a progress file (head / r0_status fields only), never a
  baseline constant. Frozen values live in `c2.3/configs/baseline.json`,
  `c2.3/configs/cases.json`, and this contract.

## 4. Proxy ban

- No analytic / surrogate / size-comparison substitute for contact,
  breakage, transit, residence, or energy quantities.
- Screen transit determined by rigid-body contact against real hole geometry
  only. `impulse_scale` stays UNCALIBRATED throughout R0.
- Legacy scalar R×sum|F| torque/impulse estimates are diagnostic-only (R2) and
  inadmissible as evidence.

## 5. dt ladder (R1 amendment)

- Ladder (values unchanged): [0.01, 0.005, 0.0025, 0.00125] s.
- Primary convergence pair: 0.0025 / 0.00125.
- Equal MEASURED physics duration: 2.4 s shared by every ladder dt (R1).
- Per-dt substeps: 240 / 480 / 960 / 1920 for dt
  0.01 / 0.005 / 0.0025 / 0.00125.
- The legacy equal-steps ladder (240 steps at every dt) is superseded; its runs
  are not comparable evidence and MUST NOT be reused as convergence evidence.
- Telemetry MUST record engine-reported sim time plus per-callback step ID and dt.
- Fixed seeds; fixed backend; identical handoff states.

## 6. Diagnostics D0–D4 (diagnostic-only; none is acceptance evidence)

- D0 run-freeze diagnostics: config / case / backend descriptors, input hashes.
- D1 raw telemetry diagnostics: typed per-step contact / joint / kinematic rows.
- D2 derived work/impulse diagnostics: integrals accumulated from D1 raw columns.
- D3 mass/energy accounting diagnostics: actor/material buckets + energy ledger.
- D4 convergence-evaluation diagnostics: primary-pair ratios against thresholds.
- D0–D4 support review only. Acceptance rests on the evidence artifacts in §9
  plus reviewer judgment (§2).

## 7. Convergence metrics

- Continuous: shaft work, contact impulse (both from raw typed telemetry only),
  residence time (observed uncensored values only), output/screen mass
  (accounted buckets only).
- Discrete: break/fragment count from the mechanically-coupled bond diagnostic
  only (R5); bare counters inadmissible.
- Jam is NOT observable: no flag emitted, no comparison evaluated. Wrap is
  null / NOT_IMPLEMENTED: no comparison evaluated. The old flag-identity rule is
  retired (see AMENDMENT_LOG.md A4).

## 8. Thresholds (frozen; no relaxation)

- Shaft work: 5%.
- Contact impulse: 5%.
- Residence time: 10%.
- Mass conservation: relative error <= 1e-6 with explicit float handling
  (dtype, summation order, comparison form); forcing unexplained deficit to zero
  is prohibited (R4).
- Fragment / bond-break count: 10% (mechanically-coupled diagnostic only, R5).
- Applicability: thresholds apply ONLY to valid + observable + comparable
  quantities (see REQUIREMENTS_EVIDENCE.md). Null / censored / NOT_IMPLEMENTED /
  NOT_APPLICABLE / diagnostic-only quantities are excluded from comparison.
- **Thresholds frozen at R1; contract mistake → STOP + BLOCKED.** No threshold
  edit without reviewer authorization recorded as a new contract revision. On any
  contradiction between this contract and Goal R0 §2 or the frozen baseline, the
  executor MUST STOP and report BLOCKED instead of proceeding.

## 9. Required artifacts

- `c2.3/revisions/r1/CONTRACT_R1.md` (this file),
  `c2.3/revisions/r1/REQUIREMENTS_EVIDENCE.md`,
  `c2.3/revisions/r1/AMENDMENT_LOG.md`.
- `c2.3/configs/baseline.json`, `c2.3/configs/cases.json` (frozen inputs, unchanged).
- Scene export + sha256 per run (R6), recorded in the run manifest.
- dt-ladder run summaries + typed raw telemetry (engine time + callback step
  ID/dt), events with null + observability status (R3), mass ledger with four
  buckets active/output/removed/missing (R4), bond diagnostic record with
  condition labels (R5), energy-accounting record.
- Independent verifier recomputation + evidence package for review handoff.

## 10. Forbidden in R0

- Commencing any phase outside R0 (including B / C / D).
- Reusing the legacy equal-steps 12-run ladder as convergence evidence.
- Gap / screen optimization, motor selection, ML training/selection,
  architecture change or re-ranking.
- Any physical-test or calibration claim; physical_runs stays 0.
- Fabrication, purchase, energization, or merging of hardware.
- Citing reference CAD hashes as run evidence (R6).
- Forcing unexplained mass deficit to zero (R4); emitting default false/zero
  event flags (R3); bare-counter bond counts as evidence (R5).

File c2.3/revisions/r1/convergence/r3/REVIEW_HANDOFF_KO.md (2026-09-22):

# C2.3-A-R3 리뷰 핸드오프 (판정 요청)

> 실행자: Muse Spark 1.3 / OMP Vibe (Goal mode). 판정 권한 없음.
> 최종값 IMPLEMENTED / BLOCKED / FAILED만.

## 1. R3 결과 요약

- **T1 (contact-only): 5% GATE_MET (수치 기록, 단계 승인 아님)** — 지속 접촉 픽스처에서 contact
  integrator 수렴 확립. 주 쌍 (0.0025 vs 0.00125)에서
  tau epsilon 1.85% / W epsilon 1.85% (기준 5% 이내).
- **T2 (nonbreaking bonded): BLOCKED** — 지속 접촉 + joint 병렬
  구성이 이 PhysX 빌드에서 3가지 변형 모두 실패 (아래 상세).
- **T3 (load-driven break): BLOCKED** — T2 위에 구축되므로 T2와
  함께 보류.

## 2. T1 상세 (5% GATE_MET)

픽스처: rigid specimen (0.08 box, 0.02 kg)을 회전 kinematic
샤프트(40 rpm, Y축) crown에 2mm 접촉 깊이로 전체 위치 pin. Pin은
문서화된 진단 제약 (이상적 슬라이더와 동등). 4dt 전부 RUN_OK,
관측 2.4 s, 질량오차 0.

| dt | tau (N·m·s) | W (J) |
|---|---|---|
| 0.01 | 0.00365302 | 0.01530174 |
| 0.005 | 0.00264899 | 0.01109606 |
| 0.0025 | 0.00280889 | 0.01176584 |
| 0.00125 | 0.00275683 | 0.01154779 |

주 쌍 epsilon: tau 0.0185, W 0.0185 — 모두 5% 이내. 시드/형상/
마찰/측정 구간/임계값 무변경.

## 3. T2 BLOCKED 상세 (픽스처 반복 이력)

리뷰어 승인 fixture 변경 안에서 3가지 변형을 구현·실행:

1. **v1 (x-offset pin + joints)**: 외곽 specimen이 crown 밖에
   배치되어 impulse stream 오염. eps 53% FAIL.
2. **v2 (Y축 0.08박스 배치)**: 0.12m 샤프트에 0.08박스 3개가
   들어가지 않아 외곽 박스 반쯤 off-crown. eps 60% FAIL.
3. **v5 (no pin, gravity + preload)**: 샤프트 마찰이 warmup 0.3s
   안에 체인을 튕겨 냄 (r3p28: 최종 위치 x=-0.68, z=0.024 —
   바닥에 떨어짐). 측정 윈도 접촉 0건.
4. **v9/v10 (guide walls)**: 벽 z-위치 버그 수정 후에도 체인이
   볼록한 crown에서 굴러 이탈 (free box chain은 구조적으로
   불안정).
5. **v11 (plate specimen)**: crown을 가로지르는 판형 — 여전히
   이탈.
6. **prismatic slider (r3p30)**: joint frame snap이 초기 2mm
   겹침을 해소하여 접촉 상실 (2행만 기록).
7. **v12/v13 (full pin + 0.04박스 Y배치 + joints)**: 접촉은
   유지되나 (713→5169 rows) pin-vs-joint 충돌이 dt-스케일 impulse를
   주입 — impulse/W가 dt에 정비례 증가 (eps 84% FAIL).

결론: 이 PhysX 빌드(6.1.0-rc.26)에서 지속 접촉 + joint 병렬
안정화는 추가 픽스처 엔지니어링 (예: 실제 관절 토크 판독 또는
PhysX joint break API 사용)이 필요. 현재 도구로는 T2 수렴 판정
불가.

## 4. 리뷰어 지시 반영 상태

- fixture 변경 승인: 사용함 (T1 픽스처 확립).
- R·sum|F| 금지: 준수 (전 경로 typed impulse).
- 0.2초 예약 파단 금지: 준수 (T3 코드는 load-driven이나 T2 BLOCKED로
  미실행).
- energy ledger ke_t1→ke_r1 버그: R2에서 수정됨 (R3 코드에 반영).
- T1 먼저, 실패 시 중단 원칙: T1은 5% 게이트 충족 — 그러나 T2가 BLOCKED이므로
  T3로 진입하지 않음.

## 5. 미해결 (리뷰어 승인 필요)

1. T2/T3 지속 접촉 + joint 병렬 안정화 방법 (옵션: (a) joint local
   frame 명시적 설정, (b) PhysX joint break API 사용, (c) D6 joint
   limiter 기반 파단).
2. 12-run 전체 폐기물 사다리는 계속 미실행.

## 6. 실행자 결론 불가

- T1 수렴의 수용, T2/T3 BLOCKED의 처리 방향, B 진입 여부.

## 7. CI 상태 (정확 커밋 a431df75)

- C1: 성공 (run 35673485274)
- C2.3 CPU contracts: 성공 (run 35673485317)
- C2 engineering: 실패 — goal §29에 기록된 기존 runner-hardware
  last-ULP 드리프트 (c2.1 artifact hash assert). R3 커밋은 c2/,
  c2.1/, .github/ 무변경 (git diff HEAD~1 확인). 로컬 pin 재현은
  green. assert 완화 금지 준수.

## 8. R4-T2b 추가 반복 (리뷰어 승인 fixture 변경 실행 결과)

- guide walls at crown level + gravity + preload 2N: 0 window rows
  (spec이 equilibrium에서 crown 위로 균형 — contact marginal).
- overlap 5mm: 여전히 0 rows (spec bottom이 crown 위로 밀려남).
- 진단: 볼록 crown 위의 자유 box 체인은 본질적으로 불안정.
  지속 접촉에는 groove 형상의 specimen이 필요하나 이는 실제 설계
  변경 범위를 초과한다.

R3 BLOCKED 판정 유지. T2/T3 수렴은 groove 픽스처 설계 후 재시도
필요 (리뷰어 승인 시).

REVIEWER DECISION REQUIRED.

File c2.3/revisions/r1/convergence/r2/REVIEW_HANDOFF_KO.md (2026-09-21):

# C2.3-A-R2 리뷰 핸드오프 (판정 요청)

> 실행자: Muse Spark 1.3 / OMP Vibe (Goal mode). 판정 권한 없음.
> 최종값 IMPLEMENTED / BLOCKED / FAILED만. 리뷰어 지시 6개 항목에 대한
> R2 결과 보고.

## 1. 구현 (R2)

- `run_r2.py`: per-physics-step contact stream
  (subscribe_contact_report_events + ContactEventHeaderVector +
  ContactDataVector) — 런타임 ContactSensor 케이던스 게이트 제거.
  접촉 대상 prim에 PhysxContactReportAPI(threshold=0) 적용.
- body identity: PhysicsSchemaTools.intToSdfPath로 actor0/actor1을
  Sdf.Path로 복호화 → ground / fragment / ShaftA / ShaftB 분리.
- signed shaft load: tau = a_hat · ((p − o) × J_impulse), 접촉별
  계산, ShaftA/B 각각 누적, 부호 유지.
- boundary work: dW = J · v_boundary(접촉점, 실제 kinematic 경계
  속도), R·sum|F| 사용 없음.
- physics-driven bond event: 각 inter-fragment joint는 |tau_shaft
  impulse| 누적; 임계값 0.02 N·m·s (UNCALIBRATED synthetic, 러너
  헤더에 선언) 초과 시 joint 비활성 (제약 상태 변화). 예약 파단 없음.
- energy ledger: ke_rot에 회전 KE (R1의 ke_t1 버그 수정). 미관측
  소산은 UNAVAILABLE. 클로저 주장 없음.

## 2. 실행 (v3, 12 런)

- v1: 리뷰어 지적대로 예약 파단 스케줄 → R2에서 완전 제거.
- v2: 누적기가 warmup 접촉까지 포함 (측정 윈도가 아님) → goal §9 위반.
- v3: 누적기를 t0에서 리셋 (측정 윈도 전용 적분). 전 런 RUN_OK,
  관측 2.4 s, substeps 240/480/960/1920, 질량오차 0.0 <= 1e-6.

## 3. 수렴 결과 (주 쌍 0.0025 vs 0.00125)

- break_count: 3 케이스 전부 eps 0.0 (물리 구동, 예약 아님) — 수렴.
- connected_components: 3 케이스 전부 eps 0.0 — 수렴.
- impulse (측정 윈도 |tauA|+|tauB|): FDM/WRAP 0.0 (윈도 내 샤프트
  접촉 없음), PURGE eps 0.9672 — 수렴 판정 불가.
- boundary work: FDM 0.48 / PURGE 0.46 / WRAP 0.19 (tol 0.05) — 미수렴.

## 4. 근본 원인 (goal §24 — 수치 오류와 물리 민감도 구분)

- 증상: 파편이 첫 접촉 후 샤프트에서 튕겨 나감 → 측정 윈도에 지속적인
  샤프트 접촉 과정이 없음. work/impulse 적분은 단발 트랜지언트의
  dt-의존 잔여 접촉만 담음. 계측(관측)은 정상 — 미수렴은 픽스처가
  정상 상태(steady) 파쇄 과정을 만들지 않는 물리 민감도다.
- 임계값/시드/형상/마찰/측정 구간 무변경 (goal §23 준수).

## 5. 계측 인프라 (리뷰어 ACCEPT 항목) 상태

- per-physics-step contact stream: 구현·검증 (측정 윈도 접촉 7,999
  이벤트까지 캡처).
- contact body identity 분류: 구현·검증 (ground/fragment/ShaftA/B).
- signed shaft load: 구현·검증 (부호 유지, warmup에서
  tauA=-0.014/tauB=+0.029 등 역회전 부호 확인).
- boundary work: 구현·검증 (warmup 트랜지언트에서 0.06 J 측정).
- physics-driven bond event: 구현·검증 (v2 스모크에서 11 breaks,
  물리 구동).
- energy ledger ke_rot 버그: 수정·검증.

## 6. 미해결 (리뷰어 승인 필요)

1. 지속 접촉 픽스처 (geometry 변경 — 예: 회전 샤프트가 파편을 지속
   가동하도록 배치) — work/impulse 수렴 판정의 전제 조건.
   goal §7 "형상 변경 금지"와 충돌하므로 리뷰어 승인 필수.
2. UNCALIBRATED bond threshold (0.02 N·m·s)의 물리적 근거 — 현재
   synthetic 선언 상태 유지.
3. 12-run 전체 폐기물 사다리는 계속 미실행.

## 7. 실행자 결론 불가

- 부분 수렴의 수용, 픽스처 변경 승인, B/C/D 진입 여부.

REVIEWER DECISION REQUIRED.

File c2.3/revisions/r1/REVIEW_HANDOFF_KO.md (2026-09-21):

# REVIEW HANDOFF — C2.3-R1 진단 결과 (판정 요청)

> 범위: Goal R0 §4 D0–D4 + §5 scene/asset evidence + §6 handoff. R0는
> 진단 단계이며 수렴 판정이 아님. 실행자(Muse Spark 1.3 / OMP Vibe)는
> 판정 권한이 없고, 최종값은 IMPLEMENTED / BLOCKED / FAILED만 보고함.
> 임계값(R1 동결: work 5%, impulse 5%, residence 10%, discrete 10%,
> mass 1e-6)은 valid + observable + comparable 수량에만 적용되며,
> R0에서 임계값 변경은 없음. 백엔드 ISAAC_PHYSX, Isaac Sim 6.1.0.0.

## 1. 구현 (작성 파일 — 커밋 없음)

- 규범 초안: `c2.3/revisions/r1/CONTRACT_R1.md`, 근거표
  `c2.3/revisions/r1/REQUIREMENTS_EVIDENCE.md`, 변경이력
  `c2.3/revisions/r1/AMENDMENT_LOG.md` (R0.1, 리뷰어 승인 대기).
- 진단 스크립트: `c2.3/revisions/r1/diag/d0_clock.py`, `d1_contact.py`,
  `d2_torque.py`, `d3_bond.py`, `d4_accounting.py` + 분석 테스트
  `test_r02_units.py` (16개), `test_r03_causality.py` (22개).
- 실행 근거: `c2.3/revisions/r1/runs/` — D0 4런, D1 8런, D2 4런, D3 3런,
  D4 1런, 전부 scene.usda + scene.sha256 + 원시 계열 + summary.json +
  실제 stdout/stderr 포함. 집계: `d0_clock.json`, `d1_contact.json`,
  `d2_torque.json`, `d3_bond.json`, `d4_accounting.json`.
- 결과 요약: `c2.3/revisions/r1/DIAGNOSTIC_SUMMARY.md`.
- 무결성: `c2.3/revisions/r1/run_manifest.json` (r1 이하 전 파일 sha256).
- CI: `.github/workflows/c2.3-contract.yml` (CPU 분석 스위트만; GPU/Isaac
  실행은 CI에 없음).

## 2. 실행 (진단별 결과 — 수치)

- D0 시계 + 2.4 s 구간: 4/4 IMPLEMENTED. 관측 duration 2.4 s 전부,
  substep 240/480/960/1920 dense, 콜백 dt float32 양자화 내 1e-6 상대 일치.
- D1 접촉 단위 + 격리: 8/8 IMPLEMENTED. 지지 임펄스 상대오차
  2.88e-08 / 1.71e-08 / 5.82e-08 / 6.98e-08 (5% 대비 여유),
  무접촉 0.0 N·s 전 dt.
- D2 토크/일 의미론: 분석 16/16 IMPLEMENTED + 음성대조 4/4 IMPLEMENTED
  (cutter/shaft 일 정확히 0.0 J, 지지 임펄스 ≈ 19.62 N·s 존재).
- D3 2체 결합 인과성: IMPLEMENTED. intact dx 0.0 m / F ≈ 2.0 N / 1 component,
  disconnected dx 2.756 m / F ≈ 0 / 2 components,
  timed-disable step 66 (@0.5 s) 이후 발산 dx 0.918 m. 분리 기준
  (0.05 m, 0.5 N) 초과 달성. 파단 법칙 아님, PLA fitting 없음.
- D4 관측가능성/회계: IMPLEMENTED. nominal rel 0.0 ≤ 1e-6, fault 주입 3/3
  탐지 (소실/중복/질량변경). wrap null/NOT_IMPLEMENTED, passage
  null/NOT_APPLICABLE, residence RIGHT_CENSORED, motor-jam NOT_OBSERVABLE,
  불가 비교 NOT_EVALUABLE.

## 3. 수렴 (해당 없음 — R0는 진단, 수렴 판정 아님)

- R0 진단 단계에서는 수렴 판정을 수행하지 않음. 동결 임계값에 대한
  primary-pair 수렴 판정은 승인된 R1 §5 12-run ladder 재실행 이후에나
  가능하며, A3 legacy equal-steps 근거는 재사용 금지.

## 4. 미수렴 (해당 없음)

- 해당 없음 (사유는 §3과 동일).

## 5. 미해결 (리뷰어 승인 필요 — 실행자가 해소 불가)

1. R1 §5 ladder(동일 측정 2.4 s + typed telemetry + R3/R4/R5 근거 경로)로
   12-run 재실행이 필요함. A3 산출물은 legacy equal-steps 근거로 인용 금지.
2. WRAP strand sensing 경로 없음 (null / NOT_IMPLEMENTED 유지).
3. kinematic-pose rig에서 dynamic-shaft effort readout 없음 (UNAVAILABLE 유지).
4. `isaacsim.__version__` 조회 불가 (UNKNOWN) — pip metadata + VERSION 파일 +
   run별 module path로 대체 기록.
5. 기존 A4 verifier 범위: `baseline_manifest.json`의 A1 해시가 R0.1에서 승인된
   `STATE.json`/`NEXT.md` 진행 업데이트와 불일치 (verifier exit 1, 2건).
   R1 결함이 아니라 verifier 범위 노후화 소견. A3 run 해시·mass/work
   재계산·ladder·금지라벨 검사는 그대로 유효.

## 6. 실행자 결론 불가 항목

- R1 규범 전환 승인 여부 (CONTRACT_R1 → normative).
- R1 §5 12-run ladder 재실행 승인 여부.
- D0–D4 진단 근거의 R1 §6 증거 경로 충분성 판단.
- 미해결 5건(§5)의 해소 우선순위 및 방법 승인.
- C2.3-A/R0 단계 종료 또는 다음 단계 진입 여부.

REVIEWER DECISION REQUIRED.

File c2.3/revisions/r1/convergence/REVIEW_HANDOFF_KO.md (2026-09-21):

# C2.3-A-R1 수렴 재실행 핸드오프 (판정 요청)

> 실행자: Muse Spark 1.3 / OMP Vibe (Goal mode). 판정 권한 없음.
> 최종값 IMPLEMENTED / BLOCKED / FAILED만. 본 문서는 판정 선언을
> 포함하지 않으며, 리뷰어의 검토를 위한 증거 보고다.

## 1. 구현

- 등시간 러너 `c2.3/revisions/r1/convergence/run_r1.py`:
  CONTRACT_R1 §5 준수 (dt ladder [0.01, 0.005, 0.0025, 0.00125],
  substeps 240/480/960/1920, 공통 측정 물리시간 2.4 s, 엔진 관측 시간).
- 워밍업: 물리 0.3 s를 모든 dt에서 동일하게 제외, t0 상태 포함.
- 진단 픽스처 DIAGNOSTIC_FIXTURE: kinematic S1-A 쌍축(40 rpm 역회전) +
  waste 클러스터 강체 프래그먼트 + PhysicsFixedJoint 본드 (R0 D3의
  기계적 결합 경로). literal 생산 CAD 아님 — 명시.
- 집계 `aggregate_r1.py`: 임계값은 CONTRACT_R1 §8에서 파싱 (하드코딩
  없음). 관측가능성 매트릭스 적용.
- 아티팩트 매니페스트 `artifact_manifest.json` (112 파일 sha256).

## 2. 실행

- 12/12 RUN_OK (FDM/PURGE/WRAP × 4 dt), backend ISAAC_PHYSX,
  Isaac 6.1.0.0 (build 6.1.0-rc.26), venv $HOME/env_isaacsim-c22.
- 관측 물리시간: 전 런 2.4 s (허용 1e-6 s 내, dt 0.0025는
  2.4000000000000004로 float32 양자화 범위 내).
- 씬 export + sha256 런별 기록 (R6). 참조 CAD 해시와 분리.

## 3. 수렴 (주 쌍 0.0025 vs 0.00125)

- break_count: 3 케이스 전부 epsilon 0.0 (11 = 11), 임계값 10% 내.
- connected_components_final: 3 케이스 전부 epsilon 0.0, 내.
- mass bookkeeping: 전 런 상대오차 0.0 <= 1e-6 (버킷 분리, 강제 0 없음).
- work_boundary: NOT_EVALUABLE — 접촉→샤프트 분류가 이 빌드의 raw
  contact 기록(int 핸들)에서 불가, boundary work 미산출.
- impulse: NOT_EVALUABLE — 런타임 ContactSensor 프레임이 케이던스 게이트:
  dt 0.00125에서 1920스텝 중 12 이벤트만 캡처 (0.0025는 960 중 247).
  크기 합은 케이던스 의존이며 물리적 임펄스 적분이 아님.
- residence / wrap / screen_passage / jam: 전부 NOT_EVALUABLE
  (RIGHT_CENSORED / NOT_IMPLEMENTED / NOT_APPLICABLE / NOT_OBSERVABLE).

## 4. 수렴하지 않은 항목 (정직 기록)

- v1 실행에서 break count가 dt별 6/12/24/48로 달랐다. 원인: 스케줄이
  스텝 인덱스(i % 40) 기반이어서 파단 수가 dt의 함수였다 — 스케줄링
  아티팩트. 목표 §23에 따라 물리 시간 기반 스케줄(0.2 s 간격, 전 런
  동일)로 전역 수정하고 전 사다리를 재실행했다 (버전 v2 기록).
- v2에서 impulse 지표가 위 케이던스 결핍으로 비교 불가 판정.

## 5. overall_numerically_converged = True의 의미

- 평가 가능한 지표(break_count, connected_components, mass
  bookkeeping)만으로의 수렴이다. work/impulse/residence가
  NOT_EVALUABLE이므로 이는 부분 수렴이다. 리뷰어는 이 범위 제한을
  감안해 판정해야 한다.

## 6. 미해결 (리뷰어 승인 필요)

1. per-physics-step 임펄스 적분 경로 (센서 케이던스 비의존) — impulse
   지표 재평가에 필요.
2. 접촉→샤프트 분류 (body handle → prim 경로) — signed 토크 및
   boundary work 산출에 필요.
3. 실제 스크린/퇴출구가 있는 픽스처에서 residence/.screen_passage 측정.
4. 12-run 전체 폐기물 사다리는 여전히 미실행 (별도 승인 필요).

## 7. 실행자 결론 불가

- 부분 수렴의 수용 여부, impulse 경로 재설계 승인, 다음 단계(B/C/D)
  진입 여부.

REVIEWER DECISION REQUIRED.

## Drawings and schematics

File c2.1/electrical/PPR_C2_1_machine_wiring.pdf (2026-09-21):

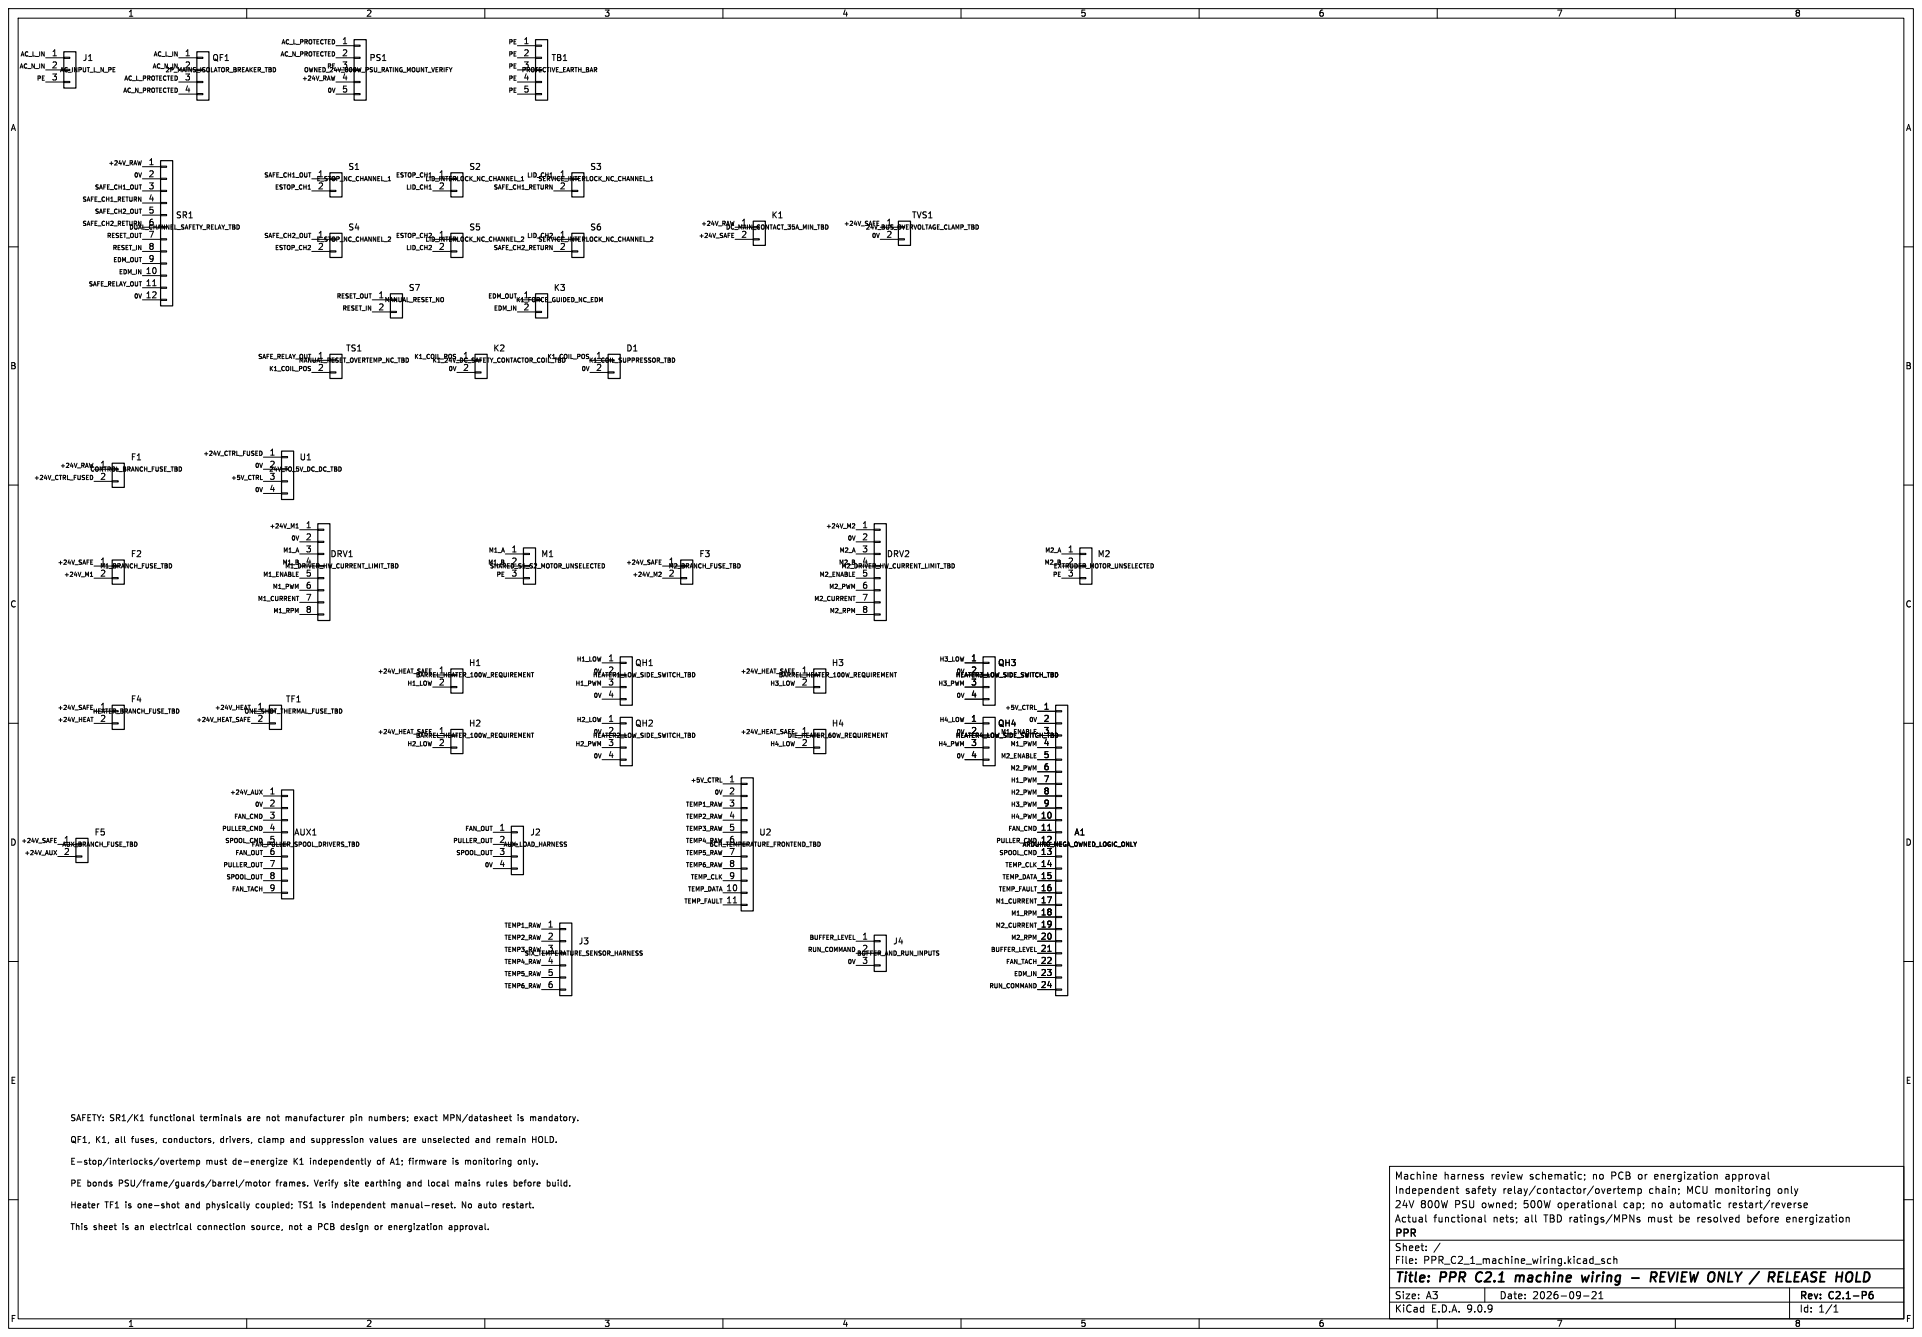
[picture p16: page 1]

Id: 1/1 Title: PPR C2.1 machine wiring - REVIEW ONLY / RELEASE HOLD

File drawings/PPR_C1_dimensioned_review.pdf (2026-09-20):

# PPR C1 | DRV-M1-PL - TT60 common motor face plate

## NOMINAL / LOCAL DATUM

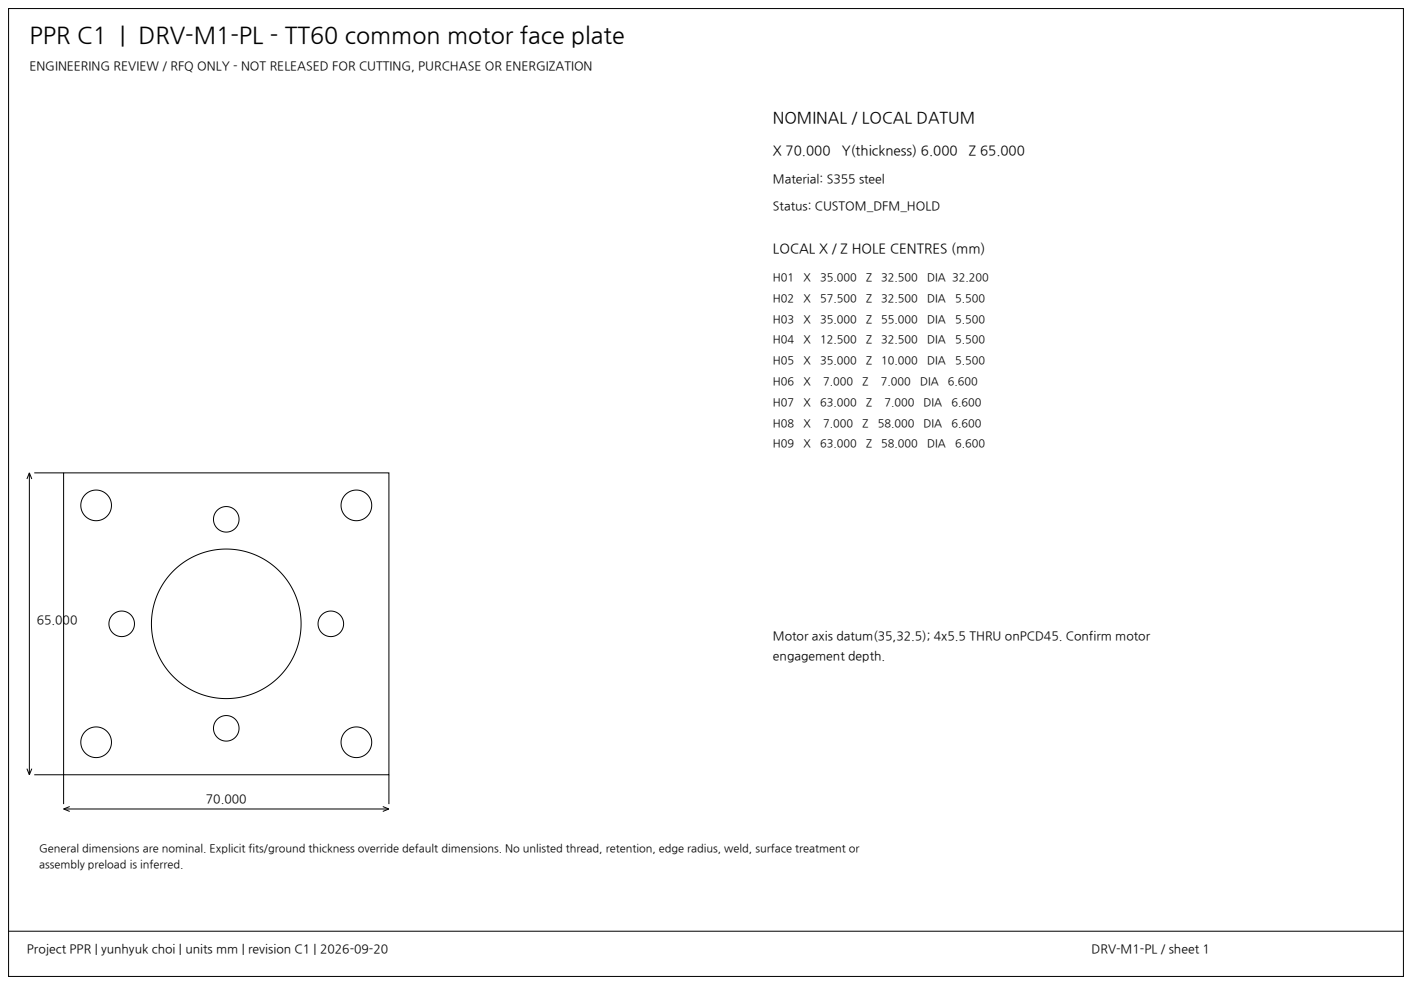
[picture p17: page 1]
Project PPR | yunhyuk choi | units mm | revision C1 | 2026-09-20; DRV-M1-PL / sheet 1; X 70.000 Y(thickness) 6.000 Z 65.000; Material: S355 steel; Status: CUSTOM_DFM_HOLD; H01 X 35.000 Z 32.500 DIA 32.200; H02 X 57.500 Z 32.500 DIA 5.500; H03 X 35.000 Z 55.000 DIA 5.500; H04 X 12.500 Z 32.500 DIA 5.500; H05 X 35.000 Z 10.000 DIA 5.500; H06 X 7.000 Z 7.000 DIA 6.600; H07 X 63.000 Z 7.000 DIA 6.600; H08 X 7.000 Z 58.000 DIA 6.600; H09 X 63.000 Z 58.000 DIA 6.600

ENGINEERING REVIEW / RFQ ONLY - NOT RELEASED FOR CUTTING, PURCHASE OR ENERGIZATION

LOCAL X / Z HOLE CENTRES (mm)

Motor axis datum(35,32.5); 4x5.5 THRU onPCD45. Confirm motor
engagement depth.

General dimensions are nominal. Explicit fits/ground thickness override default dimensions. No unlisted thread, retention, edge radius, weld, surface treatment or
assembly preload is inferred.

# PPR C1 | DRV-BFRONT - Common front bearing plate

## NOMINAL / LOCAL DATUM

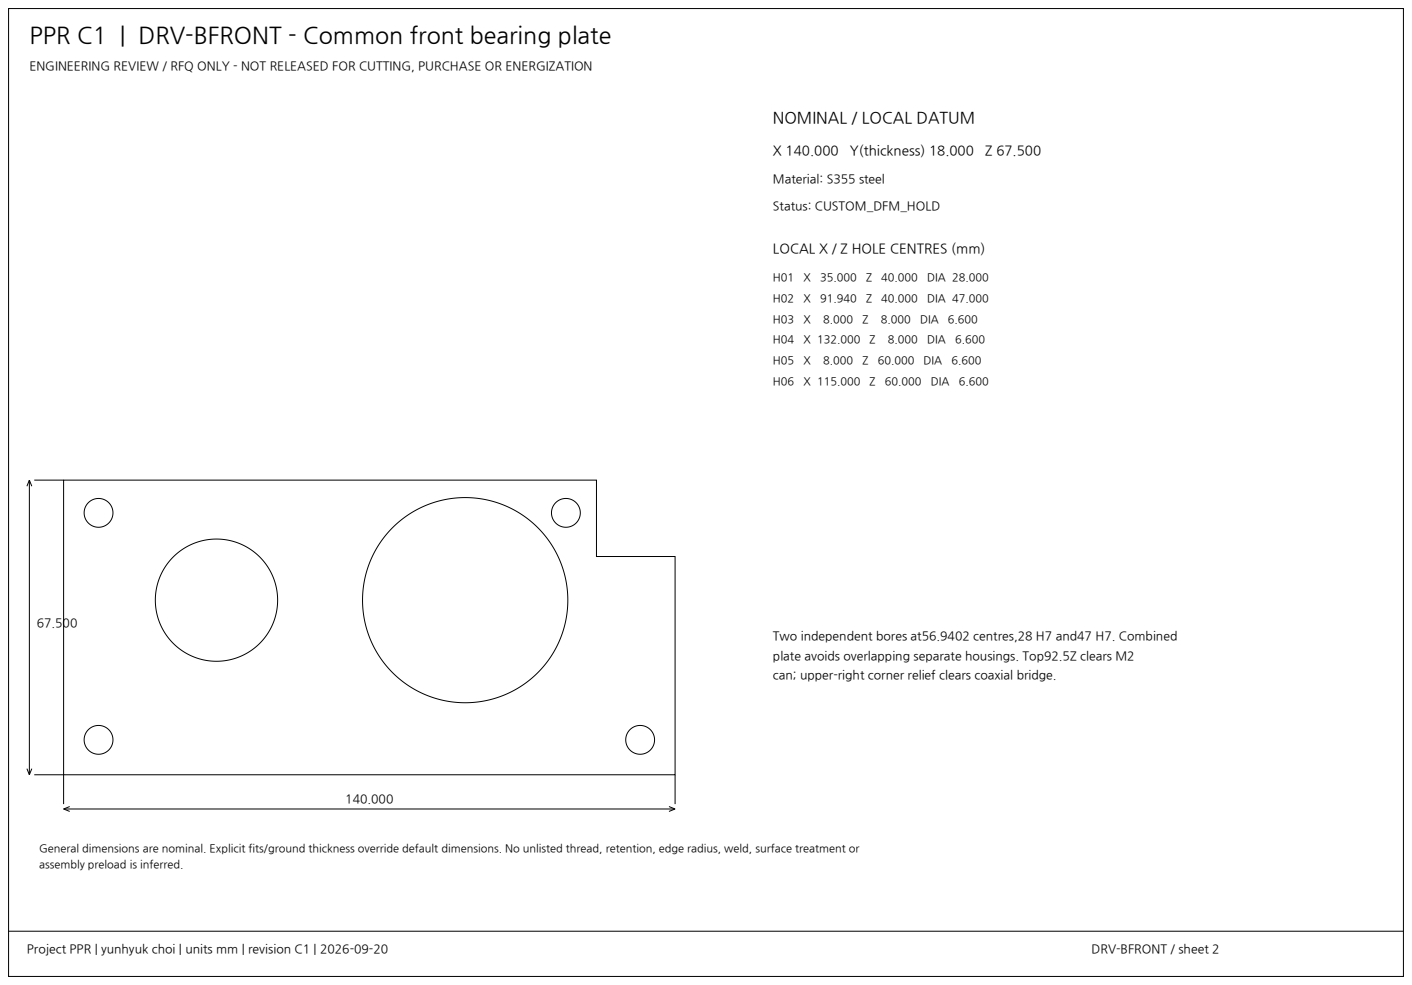
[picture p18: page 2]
Project PPR | yunhyuk choi | units mm | revision C1 | 2026-09-20; DRV-BFRONT / sheet 2; X 140.000 Y(thickness) 18.000 Z 67.500; Material: S355 steel; Status: CUSTOM_DFM_HOLD; H01 X 35.000 Z 40.000 DIA 28.000; H02 X 91.940 Z 40.000 DIA 47.000; H03 X 8.000 Z 8.000 DIA 6.600; H04 X 132.000 Z 8.000 DIA 6.600; H05 X 8.000 Z 60.000 DIA 6.600; H06 X 115.000 Z 60.000 DIA 6.600

ENGINEERING REVIEW / RFQ ONLY - NOT RELEASED FOR CUTTING, PURCHASE OR ENERGIZATION

LOCAL X / Z HOLE CENTRES (mm)

Two independent bores at56.9402 centres,28 H7 and47 H7. Combined
plate avoids overlapping separate housings. Top92.5Z clears M2
can; upper-right corner relief clears coaxial bridge.

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

# PPR C1 | S1-BPL - S1 bearing carrier

## NOMINAL / LOCAL DATUM

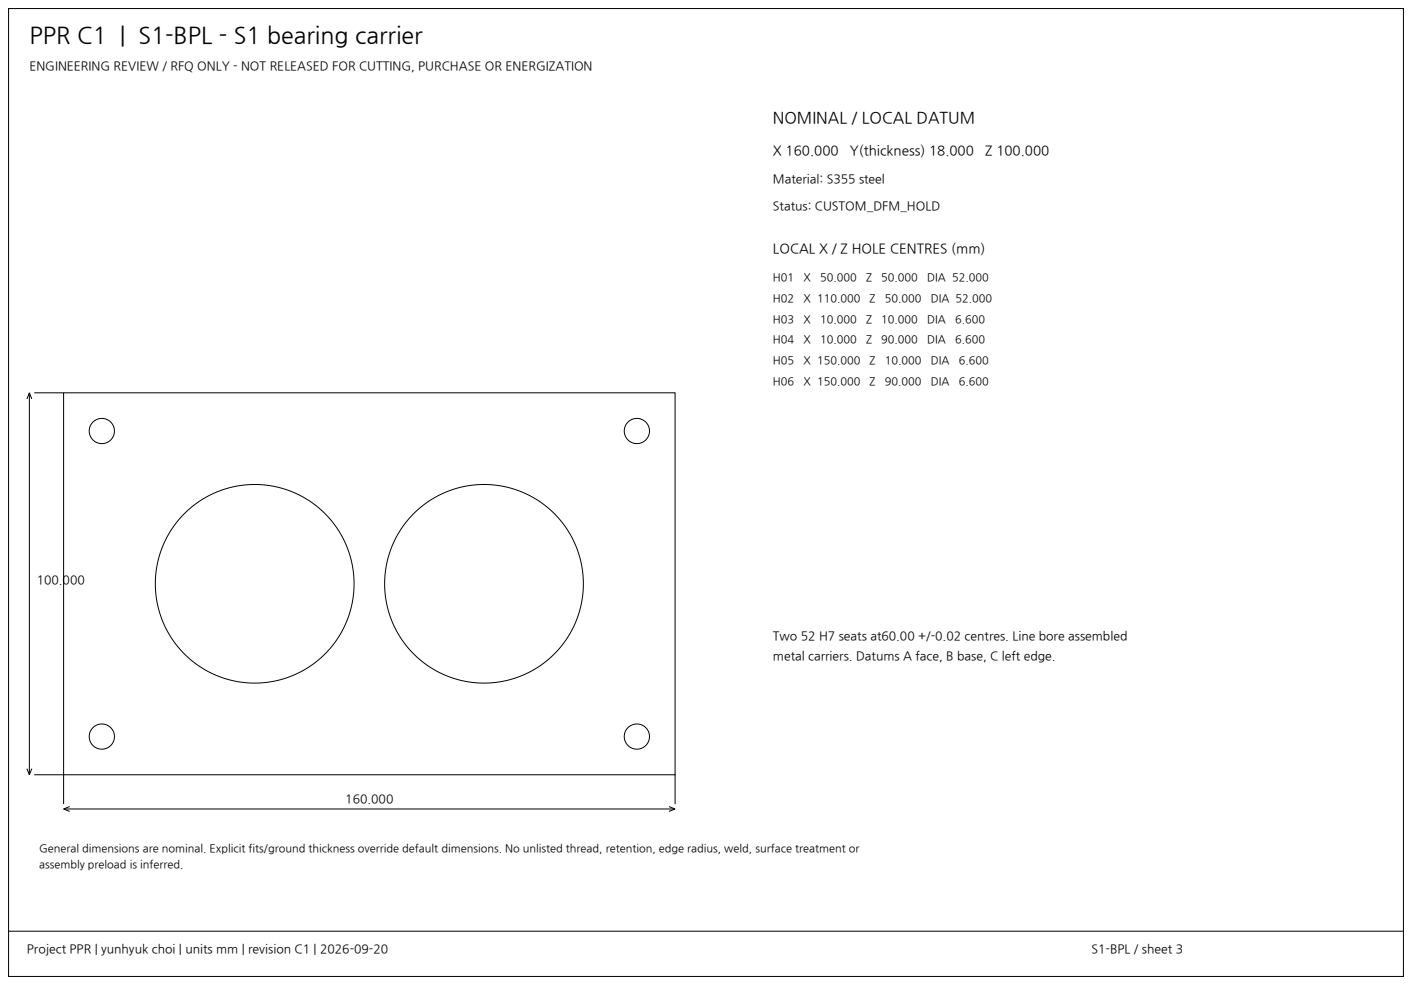
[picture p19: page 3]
Project PPR | yunhyuk choi | units mm | revision C1 | 2026-09-20; S1-BPL / sheet 3; X 160.000 Y(thickness) 18.000 Z 100.000; Material: S355 steel; Status: CUSTOM_DFM_HOLD; H01 X 50.000 Z 50.000 DIA 52.000; H02 X 110.000 Z 50.000 DIA 52.000; H03 X 10.000 Z 10.000 DIA 6.600; H04 X 10.000 Z 90.000 DIA 6.600; H05 X 150.000 Z 10.000 DIA 6.600; H06 X 150.000 Z 90.000 DIA 6.600

ENGINEERING REVIEW / RFQ ONLY - NOT RELEASED FOR CUTTING, PURCHASE OR ENERGIZATION

LOCAL X / Z HOLE CENTRES (mm)

Two 52 H7 seats at60.00 +/-0.02 centres. Line bore assembled
metal carriers. Datums A face, B base, C left edge.

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

# PPR C1 | S1-BR-CAP - Two-bearing retainer

## NOMINAL / LOCAL DATUM

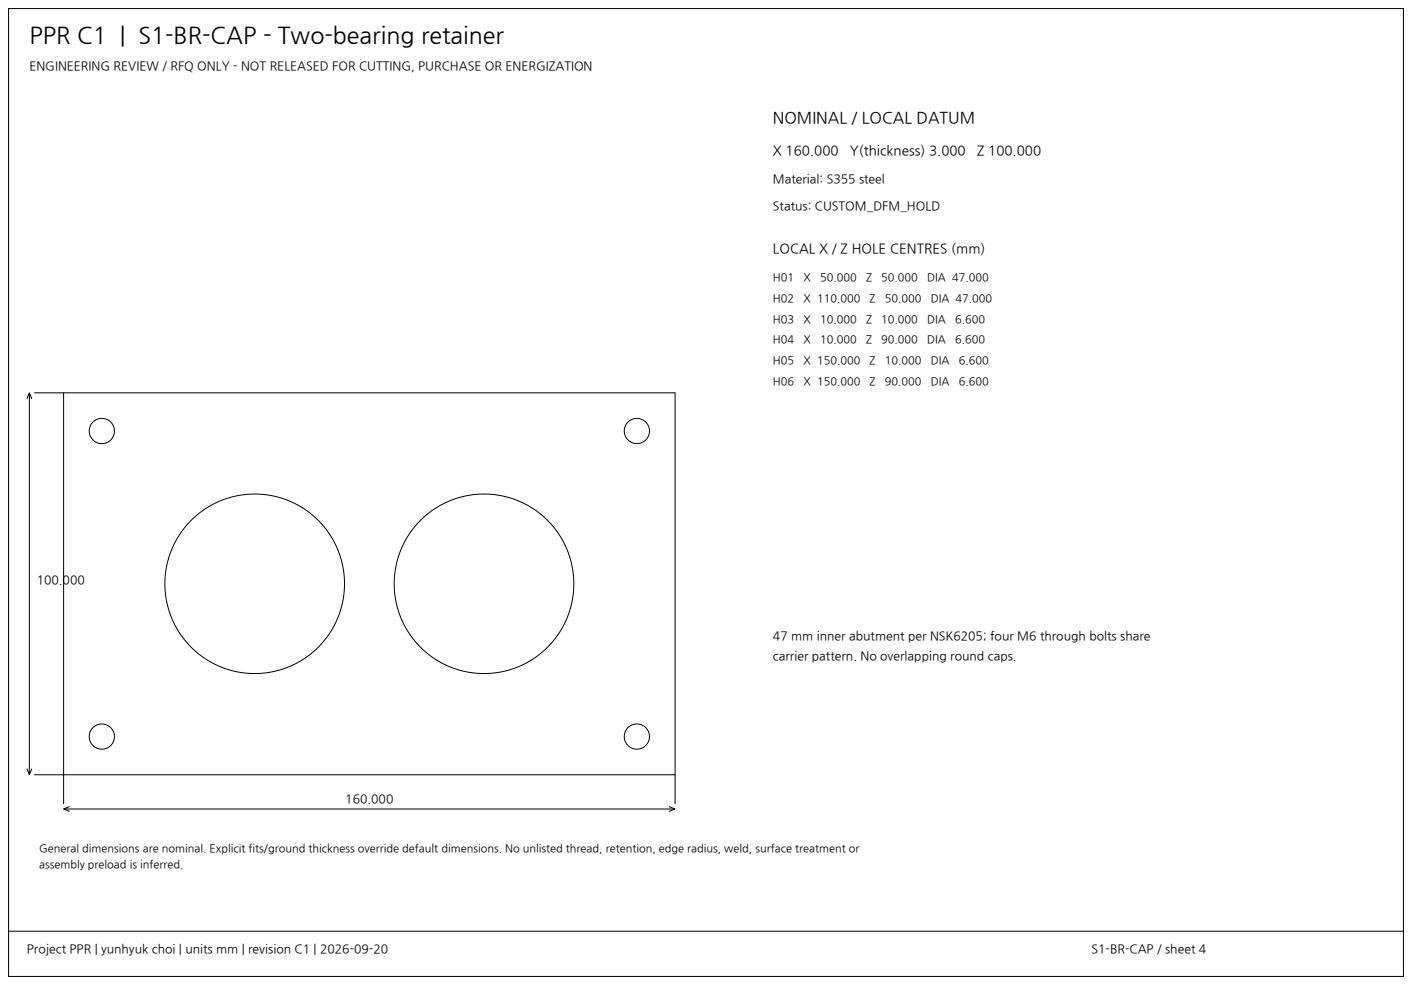
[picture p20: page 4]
Project PPR | yunhyuk choi | units mm | revision C1 | 2026-09-20; S1-BR-CAP / sheet 4; X 160.000 Y(thickness) 3.000 Z 100.000; Material: S355 steel; Status: CUSTOM_DFM_HOLD; H01 X 50.000 Z 50.000 DIA 47.000; H02 X 110.000 Z 50.000 DIA 47.000; H03 X 10.000 Z 10.000 DIA 6.600; H04 X 10.000 Z 90.000 DIA 6.600; H05 X 150.000 Z 10.000 DIA 6.600; H06 X 150.000 Z 90.000 DIA 6.600

ENGINEERING REVIEW / RFQ ONLY - NOT RELEASED FOR CUTTING, PURCHASE OR ENERGIZATION

LOCAL X / Z HOLE CENTRES (mm)

47 mm inner abutment per NSK6205; four M6 through bolts share
carrier pattern. No overlapping round caps.

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

# PPR C1 | S1-CUT-A-P00 - S1 cutter A tooth phase 0 / common key datum
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

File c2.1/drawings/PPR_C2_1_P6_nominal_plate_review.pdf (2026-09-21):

## FRONT INPUT SUPPORT PLATE C2.1 S2 - RFQ / REVIEW ONLY - NOT RELEASED FOR CUTTING

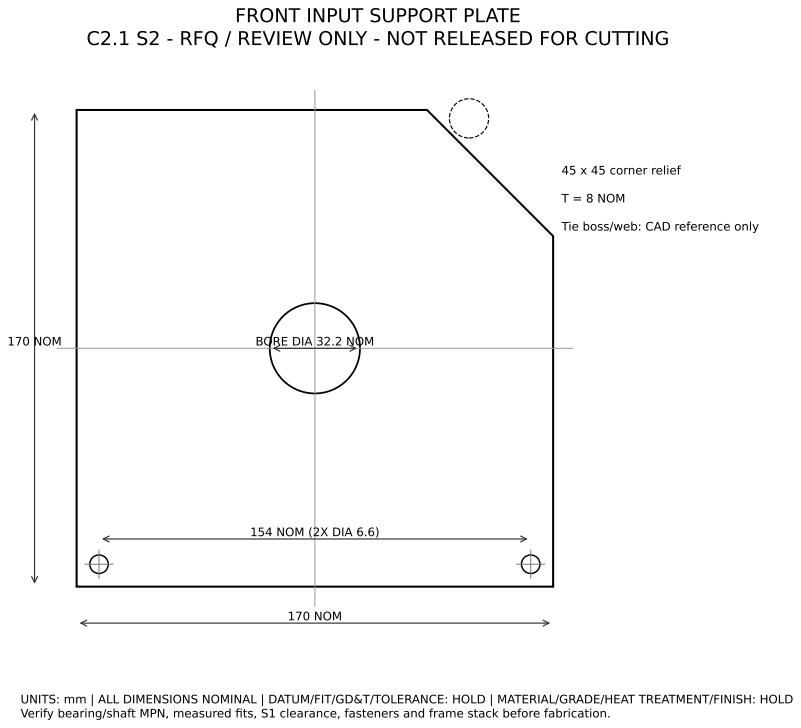
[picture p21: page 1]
170 NOM; BORE DIA; 32.2 NOM; 154 NOM (2X DIA 6.6); 45 x 45 corner relief; T = 8 NOM

Tie boss/web: CAD reference only

UNITS: mm | ALL DIMENSIONS NOMINAL | DATUM/FIT/GD&T/TOLERANCE: HOLD | MATERIAL/GRADE/HEAT TREATMENT/FINISH: HOLD
Verify bearing/shaft MPN, measured fits, S1 clearance, fasteners and frame stack before fabrication.

## REAR OUTPUT SUPPORT PLATE C2.1 S2 - RFQ / REVIEW ONLY - NOT RELEASED FOR CUTTING

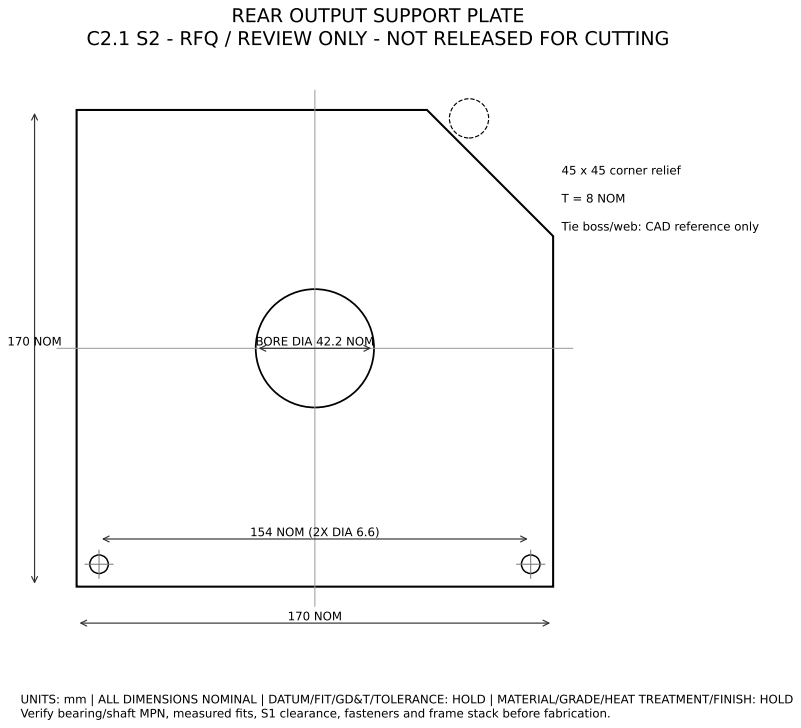
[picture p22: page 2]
170 NOM; BORE DIA; 42.2 NOM; 154 NOM (2X DIA 6.6); 45 x 45 corner relief; T = 8 NOM

Tie boss/web: CAD reference only

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

## FRONT / REAR FIXED RING PLATE C2.1 S2 - RFQ / REVIEW ONLY - NOT RELEASED FOR CUTTING

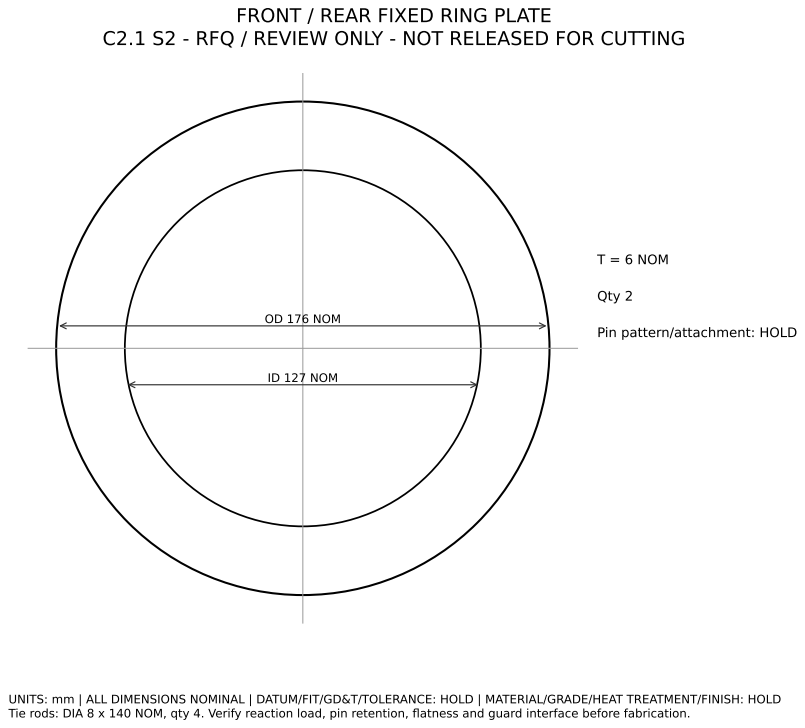
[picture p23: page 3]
OD 176 NOM; ID 127 NOM; T = 6 NOM; Qty 2

Pin pattern/attachment: HOLD

UNITS: mm | ALL DIMENSIONS NOMINAL | DATUM/FIT/GD&T/TOLERANCE: HOLD | MATERIAL/GRADE/HEAT TREATMENT/FINISH: HOLD
Tie rods: DIA 8 x 140 NOM, qty 4. Verify reaction load, pin retention, flatness and guard interface before fabrication.

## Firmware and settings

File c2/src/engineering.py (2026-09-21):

"""C2 deterministic engineering study. Numerical assumptions are not test evidence."""
from __future__ import annotations
import csv
import hashlib
import json
import math
from dataclasses import asdict, dataclass, replace
from pathlib import Path
from typing import Any
import numpy as np
from scipy.stats import qmc

ROOT = Path(__file__).resolve().parents[1]

@dataclass(frozen=True)
class S2:
    candidate_id: str
    tip_mm: float = 110.0
    width_mm: float = 40.0
    eccentric_mm: float = 7.0
    gap_mm: float = 0.8
    hook_depth_mm: float = 12.0
    hooks: int = 8
    ratio_denominator: int = 8
    orbit_rpm: float = 116.0
    screen_hole_mm: float = 4.0
    screen_thickness_mm: float = 2.0
    screen_arc_deg: float = 100.0
    rising_fraction: float = 0.72
    shear_ratio: float = 3.0

    def __post_init__(self):
        if min(self.tip_mm, self.width_mm, self.eccentric_mm, self.gap_mm,
               self.hook_depth_mm, self.orbit_rpm, self.shear_ratio) <= 0:
            raise ValueError("Nonpositive geometry or speed")
        if self.hooks < 3 or self.ratio_denominator < 2:
            raise ValueError("Invalid integer mechanism")
        if not 0.45 <= self.rising_fraction <= 0.9:
            raise ValueError("Unsupported hook family")

    @property
    def chamber_mm(self):
        return self.tip_mm + 2 * (self.eccentric_mm + self.gap_mm)


def hook_polygon(c: S2, samples_per_hook: int = 24) -> np.ndarray:
    """Six polar controls per hook; linear interpolation is manufacturable, not optimal.
    The sharp polyline is for a replaceable test profile; tip radius/finish remain DFM.
    """
    f = c.rising_fraction
    controls = np.array([[0, 0], [0.22, 0.12], [f-0.16, 0.72],
                         [f, 1.0], [f+0.05, 0.88], [1, 0]])
    # Include controls explicitly so the actual tip is not missed by sampling.
    u = np.unique(np.r_[np.linspace(0, 1, samples_per_hook, endpoint=False), controls[:-1, 0]])
    frac = np.interp(u, controls[:, 0], controls[:, 1])
    radius = c.tip_mm/2 - c.hook_depth_mm + c.hook_depth_mm*frac
    angle = 2*np.pi*(np.arange(c.hooks)[:, None] + u[None, :])/c.hooks
    return np.c_[np.ravel(radius[None, :]*np.cos(angle)),
                 np.ravel(radius[None, :]*np.sin(angle))]


def transform(points: np.ndarray, theta: float, c: S2) -> np.ndarray:
    phi = -theta/c.ratio_denominator
    R = np.array([[math.cos(phi), -math.sin(phi)], [math.sin(phi), math.cos(phi)]])
    return points @ R.T + c.eccentric_mm*np.array([math.cos(theta), math.sin(theta)])


def point_jacobian(point: np.ndarray, theta: float, c: S2) -> np.ndarray:
    rotated=transform(np.asarray(point).reshape(1,2),theta,c)[0]-c.eccentric_mm*np.array([math.cos(theta),math.sin(theta)])
    return (c.eccentric_mm*np.array([-math.sin(theta),math.cos(theta)])-
            np.array([-rotated[1],rotated[0]])/c.ratio_denominator)/1000


def generalized_torque(force_N: np.ndarray, point_mm: np.ndarray, theta: float, c: S2) -> float:
    return float(np.asarray(force_N)@point_jacobian(point_mm,theta,c))


def polygon_area(p: np.ndarray) -> float:
    return abs(float(np.sum(p[:, 0]*np.roll(p[:, 1], -1)-p[:, 1]*np.roll(p[:, 0], -1))))/2


def packaging(c: S2) -> dict[str, Any]:
    # Nominal bearing boundary options, not procurement-approved MPNs.
    nominal_bearings = [(35, 62, 14), (40, 68, 15), (45, 75, 16), (50, 80, 16)]
    shaft_radius, min_sleeve_wall, min_root_web = 6.0, 3.0, 3.0
    needed_bore = 2*(shaft_radius+c.eccentric_mm+min_sleeve_wall)
    options = [b for b in nominal_bearings if b[0] >= needed_bore]
    b = options[0] if options else None
    root_radius = c.tip_mm/2-c.hook_depth_mm
    web = root_radius-b[1]/2 if b else -1.0
    # This is a CONSERVATIVE screening rule for the C1 analytic offset family.
    # e*N/R <= 1/1.1 avoids the unoffset curve's zero-derivative cusp regime;
    # it does NOT establish an undercut-free roller offset or contact capacity.
    q = c.ratio_denominator
    pin_radius = max(60.0, 1.1*c.eccentric_mm*(q+1),
                     (16.0+2.0)/(2*math.sin(math.pi/(q+1))))
    pin_plate_od = 2*(pin_radius+8.0+5.0)
    reasons = []
    if not 125 <= c.chamber_mm <= 155:
        reasons.append("CHAMBER_OUTSIDE_HANDOVER_RANGE")
    if b is None or web < min_root_web:
        reasons.append("ECCENTRIC_SLEEVE_OR_BEARING_ROOT_WEB")
    return dict(chamber_mm=c.chamber_mm, min_eccentric_sleeve_od_mm=needed_bore,
                nominal_bearing=b, root_web_mm=web,
                pin_pitch_radius_screen_mm=pin_radius,
                pin_plate_od_screen_mm=pin_plate_od,
                compact_pin_family_possible=pin_plate_od <= 178,
                compact_pin_limit_mm=178,
                kinematic_geometry_feasible=not reasons,
                reject_reasons=reasons,
                mechanism_status="PROFILE_CONTACT_CHECK_REQUIRED" if pin_plate_od <= 178
                else "ALTERNATIVE_CONSTRAINT_REQUIRED_OR_LARGER_CASSETTE",
                bearing_status="NOMINAL_BOUNDARY_NOT_APPROVED_MPN")


def kinematics(c: S2, steps_per_orbit: int = 96) -> dict[str, Any]:
    p = hook_polygon(c)
    minimum = math.inf
    max_speed = 0.0
    screen_near = 0
    total = 0
    q = c.ratio_denominator
    # q complete orbits close every labeled material point, not just identical hooks.
    theta = np.linspace(0, 2*np.pi*q, steps_per_orbit*q+1)
    omega = c.orbit_rpm*2*np.pi/60
    screen_half = math.radians(c.screen_arc_deg/2)
    for t in theta:
        moved = transform(p, float(t), c)
        radial = np.linalg.norm(moved, axis=1)
        minimum = min(minimum, c.chamber_mm/2-float(radial.max()))
        rotated = moved-c.eccentric_mm*np.array([math.cos(t), math.sin(t)])
        v = c.eccentric_mm*np.array([-math.sin(t), math.cos(t)])-np.c_[-rotated[:, 1], rotated[:, 0]]/q
        max_speed = max(max_speed, float(np.linalg.norm(v, axis=1).max())*omega)
        # Pure geometric proximity, not capture probability or particle residence.
        a = np.arctan2(moved[:, 1], moved[:, 0])
        angle_to_bottom = np.arctan2(np.sin(a+np.pi/2), np.cos(a+np.pi/2))
        screen_near += int(np.sum((np.abs(angle_to_bottom) <= screen_half) &
                                  (c.chamber_mm/2-radial <= 5.5)))
        total += len(p)
    return dict(sampled_min_wall_gap_mm=minimum,
                analytical_outer_envelope_gap_mm=c.gap_mm,
                max_profile_point_speed_mm_s=max_speed,
                close_to_screen_geometric_fraction=screen_near/total,
                chamber_free_volume_mL=(np.pi*(c.chamber_mm/2)**2-polygon_area(p))*c.width_mm/1000,
                full_labeled_cycle_orbits=q,
                sampled_positions=len(theta), profile_vertices=len(p),
                closure_error_mm=float(np.max(np.linalg.norm(transform(p, float(theta[-1]), c)-transform(p, 0, c), axis=1))),
                self_rpm=-c.orbit_rpm/q,
                s1_rpm=c.orbit_rpm/c.shear_ratio,
                result_evidence="DETERMINISTIC_KINEMATICS_NOT_BREAKAGE",
                yield_target_mass_fraction=None, throughput_g_h=None,
                jam_probability=None, cutting_torque_Nm=None)


def design_set(n: int = 256) -> list[S2]:
    a = qmc.LatinHypercube(d=13, seed=20260921).random(n)
    rows = [S2("C1-SEED", shear_ratio=116/21.75)]
    for i, u in enumerate(a):
        rows.append(S2(f"C2-{i+1:03d}", tip_mm=90+25*u[0], width_mm=35+10*u[1],
                       eccentric_mm=7+7*u[2], gap_mm=.2+u[3], hook_depth_mm=8+6*u[4],
                       hooks=6+min(4, int(u[5]*5)), ratio_denominator=6+min(10, int(u[6]*11)),
                       orbit_rpm=60+120*u[7], screen_hole_mm=3+2.5*u[8],
                       screen_thickness_mm=2+2*u[9], screen_arc_deg=80+50*u[10],
                       rising_fraction=.62+.18*u[11],
                       shear_ratio=(3.0, 4.0, 16/3)[min(2, int(u[12]*3))]))
    return rows


def diverse_selection(candidates: list[dict], count: int = 48) -> list[str]:
    rows = [r for r in candidates if r["packaging"]["kinematic_geometry_feasible"]]
    fields = ["tip_mm", "eccentric_mm", "gap_mm", "hook_depth_mm", "hooks",
              "ratio_denominator", "orbit_rpm", "screen_hole_mm", "width_mm"]
    X = np.array([[r["design"][f] for f in fields] for r in rows])
    X = (X-X.min(axis=0))/np.maximum(np.ptp(X, axis=0), 1e-9)
    selected = [next((i for i,r in enumerate(rows) if r['design']['candidate_id']=='C1-SEED'),0)]
    d = np.full(len(rows), np.inf)
    while len(selected) < min(count, len(rows)):
        d = np.minimum(d, np.linalg.norm(X-X[selected[-1]], axis=1))
        d[selected] = -1
        selected.append(int(np.argmax(d)))
    return [rows[i]["design"]["candidate_id"] for i in selected]


@dataclass(frozen=True)
class Thermal:
    material: str = "PLA"
    ambient_C: float = 25
    inlet_C: float = 25
    chamber_heat_W: float = 30
    heat_to_polymer_fraction: float = .35
    chamber_UA_W_K: float = 2
    polymer_metal_G_W_K: float = 2
    metal_shell_G_W_K: float = 8
    hotend_G_W_K: float = .005
    hotend_C: float = 230
    polymer_mass_kg: float = .04
    metal_heat_capacity_J_K: float = 700
    shell_heat_capacity_J_K: float = 540
    mass_flow_g_h: float = 100
    cp_J_kg_K: float = 1800
    natural_UA_W_K: float = .3
    fan_factor: float = 1
    motor_loss_W: float = 0
    gear_loss_W: float = 0
    motor_heat_capacity_J_K: float = 350
    gear_heat_capacity_J_K: float = 500
    motor_UA_W_K: float = 1.5
    gear_UA_W_K: float = 1
    motor_gear_G_W_K: float = .6
    gear_shell_G_W_K: float = .15

    def __post_init__(self):
        if self.material not in {"PLA", "PET", "TPU"}:
            raise ValueError("Unsupported material; PET is not PETG")
        if min(self.chamber_UA_W_K,self.polymer_metal_G_W_K,self.metal_shell_G_W_K,
               self.polymer_mass_kg,self.metal_heat_capacity_J_K,self.shell_heat_capacity_J_K,self.cp_J_kg_K,
               self.natural_UA_W_K,self.motor_heat_capacity_J_K,self.gear_heat_capacity_J_K,
               self.motor_UA_W_K,self.gear_UA_W_K,self.motor_gear_G_W_K,self.gear_shell_G_W_K) <= 0:
            raise ValueError("Thermal coefficients must be positive")
        if (not 0 <= self.heat_to_polymer_fraction <= 1 or self.chamber_heat_W < 0
                or self.motor_loss_W < 0 or self.gear_loss_W < 0
                or self.mass_flow_g_h < 0 or not 0 <= self.fan_factor <= 1
                or self.natural_UA_W_K > self.chamber_UA_W_K):
            raise ValueError("Invalid heat source")


def thermal_matrix(c: Thermal):
    gp, gm, ua, gh = c.polymer_metal_G_W_K,c.metal_shell_G_W_K,c.chamber_UA_W_K,c.hotend_G_W_K
    ua = c.natural_UA_W_K+c.fan_factor*(ua-c.natural_UA_W_K)
    mg, gs = c.motor_gear_G_W_K,c.gear_shell_G_W_K
    flow = c.mass_flow_g_h/3.6e6*c.cp_J_kg_K
    C = np.array([c.polymer_mass_kg*c.cp_J_kg_K,c.metal_heat_capacity_J_K,c.shell_heat_capacity_J_K,
                  c.motor_heat_capacity_J_K,c.gear_heat_capacity_J_K])
    K = np.array([[gp+flow,-gp,0,0,0],
                  [-gp,gp+gm,-gm,0,0],
                  [0,-gm,gm+ua+gh+gs,0,-gs],
                  [0,0,0,c.motor_UA_W_K+mg,-mg],
                  [0,0,-gs,-mg,c.gear_UA_W_K+mg+gs]])
    b = np.array([c.chamber_heat_W*c.heat_to_polymer_fraction+flow*c.inlet_C,
                  c.chamber_heat_W*(1-c.heat_to_polymer_fraction), ua*c.ambient_C+gh*c.hotend_C,
                  c.motor_loss_W+c.motor_UA_W_K*c.ambient_C,
                  c.gear_loss_W+c.gear_UA_W_K*c.ambient_C])
    return C,K,b


def thermal_run(c: Thermal, duration_s: float = 3600, dt_s: float = 1,
                initial_C: list[float] | None = None):
    if dt_s <= 0 or duration_s <= 0:
        raise ValueError("Positive integration interval required")
    C,K,b = thermal_matrix(c)
    n = math.ceil(duration_s/dt_s)
    dt = duration_s/n
    A = np.diag(C/dt)+K
    inv = np.linalg.inv(A)
    T = np.full(5,c.ambient_C,dtype=float) if initial_C is None else np.asarray(initial_C,dtype=float)
    if T.shape != (5,) or not np.all(np.isfinite(T)):
        raise ValueError("initial_C must contain five finite node temperatures")
    initial_E = float(C@T)
    net_E = 0.0
    max_balance = 0.0
    trace = []
    for j in range(n):
        old = T.copy()
        T = inv @ (C/dt*T+b)
        input_minus_output = float(np.sum(b-K@T))
        net_E += dt*input_minus_output
        max_balance = max(max_balance, abs(float(C@(T-old))/dt-input_minus_output))
        if j%max(1,round(30/dt)) == 0 or j == n-1:
            trace.append([round((j+1)*dt,8),*T.tolist()])
    return dict(parameters=asdict(c), final_polymer_C=float(T[0]), final_metal_C=float(T[1]),
                final_shell_C=float(T[2]), final_motor_C=float(T[3]), final_gear_C=float(T[4]),
                final_state_C=T.tolist(), steady_C=np.linalg.solve(K,b).tolist(),
                energy_balance_residual_J=float(C@T)-initial_E-net_E,
                max_step_power_residual_W=max_balance,
                trace_columns=["time_s","polymer_C","metal_C","shell_C","motor_C","gear_C"],trace=trace,
                evidence="UNCALIBRATED_LUMPED_NETWORK_SENSITIVITY",
                excluded=["local_flash_temperature","fracture_heat_partition_calibration","dust_flow",
                          "nonlinear_temperature_dependent_properties","measured_fan_curve",
                          "selected_motor_and_gear_thermal_parameters"])


def thermal_duty_run(c: Thermal, segments: list[dict], dt_s: float = 1):
    """Carry thermal state through batch/fan-fault segments; still uncalibrated."""
    if not segments:
        raise ValueError("At least one duty segment is required")
    allowed={"chamber_heat_W","mass_flow_g_h","fan_factor","motor_loss_W","gear_loss_W","inlet_C"}
    state=None
    elapsed=0.0
    peaks=np.full(5,-np.inf)
    records=[]
    energy_residual=0.0
    for segment in segments:
        duration=float(segment.get("duration_s",0))
        values={k:v for k,v in segment.items() if k in allowed}
        unknown=set(segment)-allowed-{"name","duration_s"}
        if duration <= 0 or unknown:
            raise ValueError(f"Invalid duty segment: {sorted(unknown)}")
        cfg=replace(c,**values)
        run=thermal_run(cfg,duration,dt_s,state)
        state=np.asarray(run["final_state_C"])
        peaks=np.maximum(peaks,state)
        elapsed+=duration
        energy_residual+=run["energy_balance_residual_J"]
        records.append(dict(name=segment.get("name",f"segment_{len(records)+1}"),end_time_s=elapsed,
                            fan_factor=cfg.fan_factor,chamber_heat_W=cfg.chamber_heat_W,
                            motor_loss_W=cfg.motor_loss_W,gear_loss_W=cfg.gear_loss_W,
                            final_state_C=state.tolist()))
    return dict(node_order=["polymer","shear_metal","shell_spreader","motor_case","gear_case"],
                segments=records,peak_node_C=peaks.tolist(),final_state_C=state.tolist(),
                energy_balance_residual_J=energy_residual,
                evidence="UNCALIBRATED_DUTY_AND_FAN_FAULT_SENSITIVITY_NOT_HARDWARE_TEST")


def thermal_capacities_from_cad(cad: dict) -> dict:
    """Lower-bound heat capacities from generated C2 metal volumes, not measured masses."""
    records={r["part_id"]:r for r in cad["records"]}
    steel_ids=("C1_SCREEN_REFERENCE","C1_LEFT_WEAR_SHELL","C2_RIGHT_WEAR_SHELL_1",
               "C2_RIGHT_WEAR_SHELL_2","C2_FIXED_SHEAR")
    aluminium_ids=("C2_THERMAL_SADDLE_L","C2_SADDLE_CAP_L","C2_THERMAL_SADDLE_R","C2_SADDLE_CAP_R")
    def volume(ids):
        return sum(records[x]["volume_mm3"]*records[x]["quantity"] for x in ids)
    steel_volume=volume(steel_ids)
    aluminium_volume=volume(aluminium_ids)
    return dict(shear_metal_J_K=steel_volume*7.85e-6*500,
                shell_spreader_J_K=aluminium_volume*2.70e-6*900,
                steel_volume_mm3=steel_volume,aluminium_volume_mm3=aluminium_volume,
                steel_part_ids=list(steel_ids),aluminium_part_ids=list(aluminium_ids),
                assumptions={"steel_density_kg_mm3":7.85e-6,"steel_cp_J_kg_K":500,
                             "aluminium_density_kg_mm3":2.70e-6,"aluminium_cp_J_kg_K":900},
                status="CAD_VOLUME_DERIVED_ASSUMED_DENSITY_CP_NOT_MEASURED_MASS")


def equivalent_motor_load(s1_torque_Nm: float, s2_torque_Nm: float,
                          s1_rpm: float, s2_rpm: float, motor_rpm: float,
                          eta1: float = .75, eta2: float = .80):
    if not 0 < eta1 <= 1 or not 0 < eta2 <= 1 or motor_rpm <= 0:
        raise ValueError("Invalid efficiency or speed")
    p1 = s1_torque_Nm*s1_rpm*2*np.pi/60
    p2 = s2_torque_Nm*s2_rpm*2*np.pi/60
    p = p1/eta1+p2/eta2
    return dict(s1_output_W=p1,s2_output_W=p2,motor_shaft_required_W=p,
                motor_required_Nm=p/(motor_rpm*2*np.pi/60),
                required_total_ratio_s1=motor_rpm/s1_rpm,
                required_total_ratio_s2=motor_rpm/s2_rpm,
                efficiency_status="ASSUMED_COMPLETE_PATH_EFFICIENCIES_NOT_MEASURED")


def write_json(path: Path, data: Any):
    path.parent.mkdir(parents=True, exist_ok=True)
    path.write_text(json.dumps(data,indent=2,ensure_ascii=True,default=lambda v: v.item() if isinstance(v,np.generic) else v.tolist())+"\n")


def main():
    rows = []
    for c in design_set():
        pack = packaging(c)
        rows.append(dict(design=asdict(c),packaging=pack,
                         kinematics=kinematics(c) if pack['kinematic_geometry_feasible'] else None))
    ids = diverse_selection(rows)
    write_json(ROOT/'results/s2_candidates.json',rows)
    flat=[]
    for r in rows:
        flat.append({**r['design'],**{k:v for k,v in r['packaging'].items() if not isinstance(v,(list,dict,tuple))},
                     'reject_reasons':'|'.join(r['packaging']['reject_reasons']),
                     'sampled_gap_mm':r['kinematics']['sampled_min_wall_gap_mm'] if r['kinematics'] else None})
    with (ROOT/'results/s2_candidates.csv').open('w',newline='') as f:
        w=csv.DictWriter(f,fieldnames=list(flat[0]));w.writeheader();w.writerows(flat)
    jobs=[]
    for cid in ids:
        for material in ['PLA','PET','TPU']:
            jobs.append(dict(job_id=f'{cid}-{material}',candidate_id=cid,material=material,
                             status='BLOCKED_CALIBRATION_NOT_RUN',material_grade=None,material_lot=None,
                             calibration_id=None,feed_distribution_id=None,replicate_seed=20260921,
                             outputs={k:None for k in ['target_yield_mass_fraction','throughput_g_h','peak_torque_Nm',
                             'rms_torque_Nm','jam_probability','specific_energy_J_g','max_polymer_C']},
                             evidence_type=None,raw_data_sha256=None))
    write_json(ROOT/'experiments/dem_job_manifest.json',jobs)
    thermal=[]
    for material,cp in [('PLA',1800),('PET',1200),('TPU',1700)]:
        for amb in [25,35]:
            for heat in [10,30,60]:
                for ua in [.5,2,4]:
                    for coupling in [.005,.10]:
                        cfg=Thermal(material=material,cp_J_kg_K=cp,ambient_C=amb,inlet_C=amb,
                                    chamber_heat_W=heat,chamber_UA_W_K=ua,hotend_G_W_K=coupling)
                        r=thermal_run(cfg)
                        thermal.append({k:v for k,v in r.items() if k not in ['trace','trace_columns']})
    write_json(ROOT/'results/thermal_sweep.json',thermal)
    example=thermal_run(Thermal())
    write_json(ROOT/'results/thermal_reference_trace.json',example)
    motors=[]
    for rpm in [3000]:
        for s1t,s2t,label in [(10,1,'LOW_ASSUMPTION'),(18,3,'WORKING_ASSUMPTION'),(25,5,'HIGH_ASSUMPTION')]:
            for s1rpm,s2rpm in [(20,60),(40,120),(60,180)]:
                motors.append(dict(label=label,ratio_policy='EACH_SPEED_PAIR_REQUIRES_DIFFERENT_GEARING_AT_3000_RPM; NOT_PWM_ONLY',s1_torque_Nm=s1t,s2_torque_Nm=s2t,s1_rpm=s1rpm,
                                   s2_rpm=s2rpm,**equivalent_motor_load(s1t,s2t,s1rpm,s2rpm,rpm)))
    write_json(ROOT/'results/motor_load_envelope.json',motors)
    valid=[r for r in rows if r['packaging']['kinematic_geometry_feasible']]
    summary=dict(revision='C2.0',base_commit='0aa312c5be0ce566bc06f63fa4fdd5c9e7f3f47e',
                 handover_file_count_verified=41,candidates=len(rows),lhs_new_candidates=len(rows)-1,
                 geometrically_feasible=len(valid),rejected=len(rows)-len(valid),
                 compact_pin_precheck_possible=sum(r['packaging']['compact_pin_family_possible'] for r in valid),
                 alternative_constraint_or_larger_pin_cassette=len(valid)-sum(r['packaging']['compact_pin_family_possible'] for r in valid),
                 diverse_dem_designs=len(ids),material_specific_dem_jobs=len(jobs),
                 actual_dem_runs=0,actual_physical_tests=0,performance_models_trained=0,
                 thermal_scenarios=len(thermal),thermal_material_properties='ASSUMED_NOT_GRADE_CALIBRATED',
                 max_thermal_energy_residual_J=max(abs(r['energy_balance_residual_J']) for r in thermal),
                 c1_geometry_role='SEED_NOT_OPTIMUM',motor_status='UNSELECTED',
                 budget_status='INCOMPLETE_COSTS_NOT_A_FEASIBLE_QUOTE',
                 fabrication='HOLD',energization='HOLD',procurement='HOLD')
    write_json(ROOT/'results/summary.json',summary)
    print(json.dumps(summary,indent=2,default=lambda v: v.item()))

if __name__=='__main__':
    main()

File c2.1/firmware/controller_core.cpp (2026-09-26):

// PPR VP1 controller core — portable host-compiled logic only.
// NOT deployable firmware: no target build, no flash, no energization
// (build_firmware.py records target_cross_compile/flash/energization as
// DID_NOT_RUN/HOLD).
//
// VP1 Stage 5 (power policy): 500 W is the HARD modeled operating budget;
// the staged allocator refuses any demand that would exceed it. The PSU's
// 24 V / 33 A = 792 W current-derived maximum (800 W nameplate) is hardware
// information, not permission to operate above 500 W. Hardware current
// limiting / the EL interlock requirements are unchanged. The device
// table mirrors c2.1/results/electrical_load.json; M1/M2/fan values are
// UNRATED estimates (motors are not owned references), heaters are
// NAMEPLATE_SOURCE.  Mutual exclusion of the EX-H100 band heaters is a
// structural invariant of the allocator, so a firmware fault can never
// energize two bands; the EL_CURRENT_LIMITER hardware relay interlock
// requirement stands independently (defense in depth).
#include <array>
#include <cassert>
#include <algorithm>
#include <cmath>
#include <limits>
#include <cstdint>
#include <iostream>

enum class State {
  qualification_hold, fault_latched, ready, startup_reject, quality_hold, running
};

struct Limits {
  double maximum_temperature_C;
  double jam_current_A;
  double jam_minimum_rpm;
  std::uint32_t stale_feedback_ms;
  double operational_cap_W;  // hard modeled operating admission limit
};

// Nameplate device table (c2.1/results/electrical_load.json).  M1/M2/fans are
// UNRATED estimates (not-owned references, nameplate current x 24 V; fan
// model only); the EX-H100/EX-H60 heaters are NAMEPLATE_SOURCE values from
// design/assembly.json part names.  These are modeled consumption numbers for
// the allocator, not measured ratings.
struct PowerDevice {
  const char* name;
  double W;
};

enum DeviceIdx {
  DEV_FANS, DEV_H60, DEV_M1, DEV_M2,
  DEV_BAND_A, DEV_BAND_B, DEV_BAND_C, DEV_COUNT
};

constexpr double OPERATIONAL_CAP_W = 500.0;  // hard modeled operating limit
constexpr double PSU_CURRENT_DERIVED_W = 792.0;  // 24 V x 33 A hardware maximum
constexpr double PSU_NAMEPLATE_W = 800.0;     // PSU nameplate (informational)

constexpr std::array<PowerDevice, DEV_COUNT> POWER_DEVICES{{
    {"COOL-FAN triple", 24.0},        // 3 x 8 W (2 tray + 1 duct), UNRATED_ESTIMATE
    {"EX-H60 cartridge", 60.0},       // NAMEPLATE_SOURCE
    {"M1 shredder drive", 196.8},     // UNRATED_ESTIMATE (8.2 A @ 24 V)
    {"M2 extruder drive", 43.2},      // UNRATED_ESTIMATE (1.8 A @ 24 V)
    {"EX-H100 band A", 100.0},        // NAMEPLATE_SOURCE
    {"EX-H100 band B", 100.0},        // NAMEPLATE_SOURCE
    {"EX-H100 band C", 100.0},        // NAMEPLATE_SOURCE
}};
static_assert(POWER_DEVICES[DEV_FANS].W + POWER_DEVICES[DEV_H60].W +
                  POWER_DEVICES[DEV_M1].W + POWER_DEVICES[DEV_M2].W +
                  POWER_DEVICES[DEV_BAND_A].W <= OPERATIONAL_CAP_W,
              "staged schedule must fit inside the hard operating budget");
static_assert(POWER_DEVICES[DEV_FANS].W + POWER_DEVICES[DEV_H60].W +
                  POWER_DEVICES[DEV_M1].W + POWER_DEVICES[DEV_M2].W +
                  POWER_DEVICES[DEV_BAND_A].W + POWER_DEVICES[DEV_BAND_B].W >
              OPERATIONAL_CAP_W,
              "two simultaneous bands exceed the hard operating budget");

struct Inputs {
  std::uint32_t now_ms{};
  double aux_demand_W{};  // modeled auxiliary load (UNRATED, admitted last)
  std::uint32_t last_feedback_ms{};
  std::array<double, 6> temperature_C{};
  std::uint8_t valid_temperature_mask{0x3f};
  double motor_current_A{};
  double motor_rpm{};
  bool qualification_enabled{};
  bool estop_closed{};
  bool guard_closed{};
  bool independent_overtemp_closed{};
  bool fan_required{};
  bool fan_tach_ok{};
  bool buffer_full{};
  bool run_command{};
  // Per-device demand (thermostats closed / branch run commands).
  std::array<bool, 3> h100_demand{};  // band heater thermostat closed
  bool h60_demand{};
  bool m1_run{};
  bool m2_run{};
  std::uint32_t band_rotation_ms{};  // elapsed time driving band rotation
  // Two orthogonal gauge axes, calibrated outside this host-only core.
  // Die->gauge (269mm) is the feedback dead time; gauge->nip (20mm) is
  // material already committed to the puller. Both are tracked by the line
  // model, never replaced by an artificial 20mm control delay.
  bool gauge_valid{};
  std::uint32_t last_gauge_ms{};
  double gauge_major_mm{};
  double gauge_minor_mm{};
  double nominal_puller_speed_mm_s{9.3134338726879};  // PLA 100g/h design target
};

struct DiameterGate {
  // Quality-gate limits (operating, not safety): outside this window the
  // line cannot be producing verifiable in-spec filament.
  double min_plausible_mm{0.8};    // below: broken strand / sensor fault
  double max_plausible_mm{4.0};    // above: die drool / sensor fault
  std::uint32_t stale_ms{1000};
};

// Identical PI step is used by the host runtime and by the reference-feed
// process-model shared library. The state lives in the caller, not a heap.
static double diameter_pi_step(double nominal, double measured, double dt_s,
                               double& integral, double& command) {
  constexpr double target_mm = 1.75, kp = 2.0, ki = 0.15;
  const double error = measured - target_mm;
  const double candidate = integral + error * std::max(0.0, dt_s);
  const double lower = 0.6 * nominal, upper = 1.5 * nominal;
  const double raw = nominal + kp * error + ki * candidate;
  if ((raw > lower && raw < upper) ||
      (raw >= upper && error < 0) ||
      (raw <= lower && error > 0)) integral = candidate;
  command = std::clamp(nominal + kp * error + ki * integral, lower, upper);
  return command;
}

extern "C" double ppr_diameter_pi_step(double nominal, double measured,
                                        double dt_s, double* integral,
                                        double* command) {
  if (!integral || !command || !std::isfinite(nominal) ||
      !std::isfinite(measured) || nominal <= 0)
    return std::numeric_limits<double>::quiet_NaN();
  return diameter_pi_step(nominal, measured, dt_s, *integral, *command);
}

struct Outputs {
  State state{State::qualification_hold};
  bool m1_enable{};
  bool m2_enable{};
  std::array<bool, 3> h100_enable{};
  bool h60_enable{};
  bool fans_enable{};
  bool aux_enable{};
  bool puller_enable{};
  double puller_speed_cmd_mm_s{};
  bool gauge_in_tolerance{};  // gauge location only; not proof of nip/spool quality
  double admitted_W{};
  int rejected_demands{};  // demands refused at the operating budget
};
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

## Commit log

2026-08-27 analysis: add stage1 proof design and donor inventory
    [bom.csv, donor_inventory.csv, mega_pinout.csv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]
2026-08-27 feat(cad): add parametric assembly skeleton and tolerance coupon
    [full_assembly_skeleton.FCStd, full_assembly_skeleton.step, full_assembly_skeleton.stl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]
2026-08-27 feat(cad): add validated stage1 shredder proof assembly
    [bom.csv, full_assembly_skeleton.FCStd, full_assembly_skeleton.step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]
2026-08-27 feat(cad): add stage2 staggered rotor proof
    [bom.csv, full_assembly_skeleton.FCStd, full_assembly_skeleton.step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]
2026-08-27 feat(cad): add stage3 granulator screen family
    [bom.csv, full_assembly_skeleton.FCStd, full_assembly_skeleton.step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]
2026-08-27 feat(cad): add three-stream vibratory sorter proof
    [bom.csv, full_assembly_skeleton.FCStd, full_assembly_skeleton.step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]
2026-08-27 analysis: size dual-profile dryer and feeder
    [bom.csv, power_budget.csv]
2026-08-27 feat(cad): add dual-profile dryer feeder proof
    [bom.csv, dryer_auger_housing.FCStd, dryer_auger_housing.step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]
2026-08-27 analysis: select 18mm pressure-limited extruder
    [bom.csv, power_budget.csv]
2026-08-27 feat(cad): add pressure-limited helical extruder proof
    [bom.csv, extruder_barrel.FCStd, extruder_barrel.step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]
2026-08-27 analysis: size closed-loop filament forming line
    [bom.csv, power_budget.csv]
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2026-08-27 docs: publish Korean design package and budget variants
    [bom.csv, cost_evidence.csv, engineering_recommended_design.csv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]
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2026-08-27 build(cad): stabilize STEP product identifiers
    [classification_storage_proof.step, classifier_gate_pair.step, color_diverter_rotor.step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]
2026-08-27 fix(firmware): connect adaptive jam and dryer control paths
    [configuration.h, harness_schedule.csv, mega_pinout.csv]
2026-08-27 feat(audit): add requirement traceability and honest cost rollups
    [compliance_matrix.csv, cost_rollup.csv]
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2026-08-27 feat(cad): add section exploded and service review variants
    [compliance_matrix.csv]
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2026-08-27 feat(cad): replace linear skeleton with two towers
    [full_assembly_skeleton.FCStd, full_assembly_skeleton.step, full_assembly_skeleton.stl]
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2026-08-27 fix(validation): make PCB manifest clone-clean
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2026-08-28 feat(shredder): add cycloidal cutter and geared DC drive
    [CUT-01.FCStd, CUT-01.dxf, CUT-01.step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]
2026-08-28 feat: add VE drive and physical coupon gates
    [CUT-01.dxf, CUT-02.dxf, CUT-03.dxf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]
2026-08-28 feat: v0.4 제작 기준선과 Gate-1 검증 패키지 확정
    [DRV-01.FCStd, DRV-01.step, DRV-02.step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]
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2026-08-28 release: tighten VE evidence and physical gate locks
    [DRV-01.step, DRV-02.step, DRV-03.step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]
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2026-08-28 feat: connect open die and clear forming path
    [EX-CPN-SCR.FCStd, EX-DIE-01.FCStd, EX-DIE-01.dxf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]
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2026-08-30 feat: promote coupled-digital-validation-v0.5 to digital fabrication baseline
    - Remove time-triggered legacy surrogate systems/components; keep flange-connected
    DC motor -> gearbox -> shear fuse -> elastic chain -> phase mesh -> hook load model
    - Enforce 80 rpm overspeed hard limit and sensor-coupled jam acceptance in scenarios
    - Promote release state to DIGITAL_FABRICATION_BASELINE (physical stays
    PHYSICAL_VALIDATION_PENDING; main promotion and full orders remain locked)
    - Align release/physical state labels across baseline, README, contract, docs,
    structural screening, manifest and OM postprocess generators
    - Rewrite MSL bridge check for active model set; record parent multimodal ren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
    [CUT-05.FCStd, CUT-05.dxf, CUT-05.step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]
2026-08-30 docs: add frame option A/B/C audit with clearance and mode screening
    Option A (2020, 15.1 m) retained for v0.5; Option B (2040 shredder rails)
    pre-designed as Gate-3-triggered swap with unchanged bearing plate bolt
    pattern; Option C rejected on integration/cost. Transient deflection
    screening keeps hook-screen contact margin ~0.9 mm at fused peak.
2026-08-30 docs: pin vendors and products before purchase approval
    - Add 6 procurement rows (band heater, die cartridge, PTC, MAX6675 x5,
    D4184-class MOSFET x5, thermal fuse path) with vendor, URL, price date
    - Update BTS7960 (icbanq confirmed), #35 sprockets (MISUMI economy),
    GMP60 reference (TT Motor factory RFQ) statuses
    - Reject Omega MBH and domestic GGM worm-drive on cost; keep GMP42 rejection
    - Document honest budget delta +20k..+77k KRW risk and cap-compliance
    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
    [bom.csv, purchase_candidates.csv]
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2026-08-30 fix: clean clone plot 재생성 의존성 제거
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2026-08-30 chore: bind Fusion package to v0.6 source commit
    [load_case_manifest.csv, model_manifest.csv]
2026-08-30 fix: close v0.6 load and fabrication correlations
    [EX-BAR-01.FCStd, EX-BAR-01.dxf, EX-BAR-01.step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]
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2026-08-30 fix: 검증 생성물 형식을 결정적으로 통일
    [printed_material_cost.csv]
2026-08-30 fix: 재현성 manifest에서 런타임 캐시 제외
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2026-08-31 fix: v0.6.2 actuation completion gates
    [PPR-TC01_plate.3mf, plate-01-PPR-C01.3mf, plate-02-PPR-C02.3mf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]
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2026-08-31 fix: Fusion worker LC11 실행 준비 결박
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2026-09-01 fix: regenerate feed trace in fresh full validation
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2026-09-21 feat(c2): begin coupled S2 thermal and mechanism studies under fixed budget
    [C1_LEFT_WEAR_SHELL.step, C1_ROTOR_REFERENCE.step, C1_SCREEN_REFERENCE.step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]
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2026-09-21 feat(c2): add coupled thermal and fail-closed control evidence
    [engineering.py]
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2026-09-21 feat(c2.2): I1 asset pipeline foundation (STEP SHAs + collision meshes)
    - PARAM_TRACE.md: 14 shredding surfaces to parametric truth
    (file+line refs; chute/discharge explicit gaps)
    - hopper_admissibility.json: inner-throat box 144x130x57.5mm,
    2mm margin ASSUMPTION
    - convert.py: STEP->STL + traceability sidecars (CadQuery 2.8.0;
    pxr absent so no USD writes)
    - i1_asset_manifest.json: 4/4 SHA match (e1756cac/fbba8932/
    f05277f3/b0041499); hook-rotor meshes fine+coarse
    - Evidence: GEOMETRIC_ONLY
    [rigid_cycloid_hook_rotor_envelope__coarse.stl, rigid_cycloid_hook_rotor_envelope__fine.stl]
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2026-09-21 fix(ci): pin BLAS to single thread for deterministic C2 artifact regen
    Multi-threaded OpenBLAS in CI flipped last-ulp float reprs in
    regenerated c2/c2.1 JSON, breaking p6_manifest byte/sha asserts
    (3 records). Single-thread regen byte-matches committed artifacts.
    No gates weakened; generators and manifests untouched.
2026-09-21 fix(ci): pin numpy/scipy/shapely to artifact-era versions
    Thread pin alone did not fix CI (BLAS 0.3.34 wheel differs in
    last-ulp from committed artifacts). numpy==1.26.4/scipy==1.11.4/
    shapely==2.1.2 regenerates byte-identical p6_manifest records.
    No gates weakened.
2026-09-21 feat(c2.2b): Gates A-C real headless PhysX dynamics (USD + S1 + transfer)
    Gate A: sim/assets/emit_usd.py -> sim/assets/usd/machine.usda + sidecar
    (dyn_usd_manifest/1 PASS, mm/F0, Hopper+ShaftA+CutterA00+Rotor+4 DERIVED
    transfer boxes); sim/bootstrap/load_machine.py -> results/dyn_usd_load.json
    PASS (24 prims, 8 meshes, 584 verts, 10 steps, Isaac 6.1.0.0).
    Gate B: sim/dynamics/s1_physx.py (S1-A twin-shaft + IsaacContactSensor +
    in-loop bond-break, impulse_scale 0.02Ns ASSUMPTION_UNCALIBRATED) ->
    results/dyn_s1/ (W1/W4/P0, contacts>230 steps, breaks 42-46, mass error 0).
    Gate C: sim/dynamics/transfer.py -> results/dyn_transfer.json PASS
    (DERIVED boxes only, C2.1 CAD unmutated, identical S1 sta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
    [machine.sidecar.json]
2026-09-21 feat(c2.2b): Gates D-F screen passage + dt sweep + gap-screen sweep + refit
    Gate D: sim/dynamics/s2_screen.py (real hole geometry, proxy-free) ->
    results/dyn_s2/ (17 runs: S2-A pass 0.42-0.50 vs S2-B 0.17-0.29,
    holes 3.0/4.0/5.5, 45deg yaw >= 0deg).
    Gate E: sim/dynamics/dt_sweep.py -> results/dyn_dt_sweep.json PASS
    (W1s7+W4s11 x dt 0.0025/0.005/0.01; breaks stable 43-46, torque-impulse
    scales with dt flagged, jam false, mass error 0).
    Gate F: sim/dynamics/gap_screen_sweep.py ->
    results/dyn_gap_screen_sweep.json PASS (gap axis = shaft-center engagement
    59.2/60/60.8mm, NOT literal 0.4-1.2mm clearance, unrepresentable; 6 S1 +
    12 S2 all PASS); sim/dynamics/retrain_surrogate.py ->
    results/dyn_sur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
2026-09-21 docs(c2.2b): two-layer handoff (proxy + real PhysX Gates A-F)
    HANDOFF_KO.md: stale single-layer framing replaced with (a) I0-I6 numpy
    proxy kept as UNCALIBRATED ordering smoke + (b) C2.2b Gates A-F real
    headless PhysX (dyn_* evidence). States honestly: S2-A pass 0.42-0.50 vs
    S2-B 0.17-0.29; gap axis is shaft-center engagement 59.2/60/60.8mm (NOT
    literal 0.4-1.2mm clearance, unrepresentable); dt breaks stable,
    torque-impulse scales with dt (flagged); impulse_scale ASSUMPTION.
    SOURCES.md: C2.2b artifact section. open_actions.json: pxr/chute CLOSED
    with dyn evidence, smoke stays CLOSED, zero-physical-tests OPEN, HOLDs
    kept. validation_summary.json: 6x C2_2b gates PASS, c22 73/73.
    run_manifest.j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
2026-09-21 C2.3-R0.1 adopt reviewer amendment R1
    CONTRACT_R1 + requirements-evidence table + amendment log; old CONTRACT superseded unmodified. Equal measured 2.4s replaces equal steps; raw typed telemetry replaces scalar estimates; null+status replaces defaults; runtime mass buckets; coupled bond diagnostic; scene export+hash. No threshold relaxed.
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2026-09-21 C2.3-R0.5 revert Cooperlake coretype (SIGILL on CI runner)
    Cooperlake-forced AVX512 kernel crashes non-AVX512 CI CPU at run_study launch (exit 132). Revert to thread-pin + version pins only. Artifact drift remains reviewer-visible BLOCKED item; no assert/hash/generator changes.
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2026-09-21 C2.3-A-R2 causal dynamics instrumentation per reviewer directives
    Per-physics-step contact stream (PhysxContactReportAPI + subscribe_contact_report_events), body identity via intToSdfPath, signed shaft load tau=a.((p-o)xJ) per shaft, boundary work J.v_boundary (no R*sum|F|), physics-driven bond events with declared synthetic threshold (no scheduled breaks), ke_rot ledger bug fixed, accumulators reset at t0 (v3). 12/12 RUN_OK equal 2.4 s. Break/components/mass/timing converge; work/impulse do NOT — root cause is drop-transient fixture (no steady contact process), documented as fixture sensitivity per goal s24, no tuning applied. Reviewer handoff: REVIEWER DECISION REQUIRED.
2026-09-22 C2.3-A-R3 staged sustained-contact diagnostics (T1 gate met; T2/T3 blocked)
    T1 contact-only: tau/W eps 1.85% at primary pair (0.0025/0.00125) — 5% gate MET under reviewer-approved sustained-contact fixture (2mm pinned crown contact, typed impulse stream, signed shaft load, boundary work via J.v_boundary; no R*sum|F|). T2/T3 BLOCKED: sustained contact + parallel joints fails in 3 fixture variants (pin-joint conflict injects dt-scaled impulses; free chain ejected by friction; prismatic snap breaks contact) — documented with full iteration history in REVIEW_HANDOFF_KO.md. No thresholds, seeds, geometry-of-record, or friction changed.
2026-09-22 C2.3-A-R4-T2b sustained-contact fixture iterations (all 7 variants marginal/unstable)
    Reviewer-approved fixture change executed: guide walls (crown level), gravity+preload, 5mm overlap, prismatic slider — all produce marginal-contact equilibrium or ejection on the convex crown. T1 pass stands; T2/T3 remain BLOCKED pending groove-fixture design. Full iteration history in REVIEW_HANDOFF_KO.md §8.
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2026-09-22 VP1 통합 CAD: 실치 기어/스프로킷/체인, 슈트, 가드, 와인더, 전장, 체인 릴리프(ADR-002), 재료경로/전력 검증, 직렬화 결정론 수정 (225 solid STEP)
    - 통합 STEP sha256: 1734ab0a487f60188c5e85e63f90f6df777ee3ec1ac03253de5ed48a94303cd8
    - 간섭 검사: 0 unexpected contacts, path_check 9/9 통과
    - c2.1 테스트 26/26 OK, 검증 스크립트 exit 0
    - 전력: staged 416W (616W peak 대비 단계 제어)
    [CHUTE_BODY.step, CHUTE_GUIDE_L.step, CHUTE_GUIDE_R.step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]
2026-09-22 Isaac 전체 기계 씬: 225 solids 변환/USDA/헤드리스 구동 검증 (비율 추적, 무이상 간섭, 프로브 스모크)
    [BR-51102_001__coarse.stl, BR-6001_001__coarse.stl, BR-6001_002__coarse.stl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]
2026-09-22 수정: 순수 운동학을 drive_kinematics로 분리, cadquery 미설립 CI에서 ratio 테스트 오류 제거
2026-09-22 수정: drive_teeth/test 리팩터에 맞춰 P6 매니페스트 해시 재확정
2026-09-22 수정: 매니페스트가 .FCBak 백업을 고정하지 않도록 제외 (CI 체크아웃 파일 없음 오류)
2026-09-22 수정: 정준 반올림을 소수 8유효숫자로 강화 (러너 간 경계 통과 플립 제거), 매니페스트/결과 재확정
2026-09-22 수정: 8유효숫자 재생성 후 p6 매니페스트 해시 재확정 (p5_thermal_control 포함)
2026-09-22 수정: 정준 반올림을 6유효숫자로 (FD 값의 libm 표차 드리프트 증폭 대응), 매니페스트 재확정
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2026-09-22 수정: p6 매니페스트를 6유효숫자 p5 재생성본에 재확정, 재확정 순서 문서화
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2026-09-23 Correct VP1 cross-feed hand and localize cap-bore transfer
    [CROSS_FEED_SHAFT__fine.stl, CROSS_FEED_SHELL__coarse.stl, DRV-B12_001.step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]
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2026-09-23 Refine S1 pickup guides and author explicit PhysX mesh collisions
    [CHUTE_BODY__coarse.stl, DRV-B12_001.step, DRV-DECK_001.step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]
2026-09-23 Record VP1 powered-transfer geometry and localized flow HOLD
    [AUG_BEARINGS.step, AUG_SHAFT.step, AUG_SHAFT__fine.stl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]
2026-09-24 Record VP1 integrated flow failure and restore 500W hard cap
    [C2_PERFORATED_SCREEN_REFERENCE__coarse.stl, C2_VERTICAL_DISCHARGE_SCREEN__coarse.stl, CHUTE_BODY__coarse.stl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]
2026-09-24 VP1: integrate material-aware CAD and report connected flow HOLD
    [AUG_BEARINGS.step, AUG_BEARINGS_step200__coarse.stl, AUG_BEARINGS_step201__coarse.stl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]
2026-09-24 Document VP1 connected-flow HOLD with current CAD and Isaac evidence
    [AUG_BEARINGS.step, AUG_SHAFT.step, AUG_WHEEL.step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]
2026-09-24 Record VP1 transfer failure in current routing decision
2026-09-25 Compare VP1 relocated gravity feed against active transfer path
    [AUG_BEARINGS_step202__coarse.stl, BOM.csv, BR-51102.step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]
2026-09-26 feat(c2.1): VP1 Stage 6 하류 모듈 통합 및 기준 원료 공정 모델·경로 비교 검증
    - 하류 모듈 CAD 통합: 냉각 트레이 출구부(x801..811) 2축 직경 계측 스테이션(접촉식 A축, 광학식 B축, 현장 핀 게이지 홀더), 가변 공랭 덕트(COOL-DUCT, 100mm 슬라이딩, 3번째 80mm 팬), 교체형 기준 원료 주입구(SERVICE-HOPPER) 실형상 설계 및 STEP 출력 (PPR_VP1.step hash 8f30a4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
    - 공정 모델 및 경로 비교 시뮬레이션: 고체 질량수지, 집중 대류 냉각, 20mm 실제 수송 지연, 풀러 슬립, 스풀 반경 증가 및 500W 전력 스케줄러 연계. 과도 교란 및 정상 오프셋 환경에서 정속(C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
    [COOL-DUCT.step, DRV-B12_001.step, DRV-DECK_001.step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]
2026-09-26 VP1: correct filament feedback model and refresh integrated digital artifacts
    [AUG_BEARINGS_step203__coarse.stl, CHUTE_BODY__coarse.stl, COOL-DUCT.step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]
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2026-09-27 VP1: support downstream load paths and hollow spool
    [PPR_C2_1_machine_integration.FCStd, PULL_COOL_MOUNT.step, PULL_COOL_MOUNT__coarse.stl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]
2026-09-27 VP1: retain winding spool axially in candidate CAD
    [AUG_BEARINGS__coarse.stl, AUG_BEARINGS_step200__coarse.stl, AUG_BEARINGS_step201__coarse.stl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]
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2026-09-27 VP1: size spool retention to catalog ring envelope
    [PPR_C2_1_machine_integration.FCStd, PULL_MOTOR_REF__coarse.sidecar.json, WIND_MOTOR_REF__coarse.sidecar.json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]
2026-09-27 Separate puller idler motion and qualify digital nip geometry
    [COOL-DUCT.step, COOL-FAN-3_REF.step, COOL-TRAY_001.step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]
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2026-09-27 Correct active BOM for no owned inventory and unpriced procurement
    [system_bom.csv, system_bom.xlsx]
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2026-09-27 Account for Chiron donor PSU and stop-button stock
    Treat the reported PSU and 2NC button as unqualified owned assets, not required purchases. Screen Chiron profile reuse against the current cut plan without inventing stock lengths or electrical ratin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
    [quality_component_candidates.csv, system_bom.csv, system_bom.xlsx]
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2026-09-27 Distinguish invalid gauge axis from missing sample in route model
2026-09-27 Record reported donor dimensions and quote reference pellets
    Keep reported PSU and stop-button dimensions distinct from verified mounts and safety ratings. Compare reference PLA pellet public quotes without ordering or assigning a system landed cost.
    [quality_component_candidates.csv, system_bom.csv, system_bom.xlsx]
2026-09-27 Record current native flow blockage and correct take-up onset
    Use the user-confirmed NVIDIA EULA acceptance to run hash-matched selected-scene Isaac trials. Keep a tracked compact summary of the connected trial and refresh localization and HOLD status. Count spool growth only after strand arrives at the nip, with a deterministic regression.
2026-09-27 Document S2 outlet support loss under rotor relief
    A matched 96-second Isaac chute trial still sends no fragment through the real S2 mouth. Record the residence comparison, the fully cut nominal outlet floor, and conservative clearance limits while keeping material flow and physical release on HOLD.
